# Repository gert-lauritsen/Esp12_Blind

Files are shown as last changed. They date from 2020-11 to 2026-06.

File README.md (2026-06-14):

# ESP12 Blind Controller

## Oversigt

ESP12 Blind Controller er en WiFi-baseret rullegardinstyring udviklet til IKEA-rullegardiner med et 3D-printet gearsystem og en stepmotor. Enheden styres via MQTT og understøtter automatisk registrering i Home Assistant gennem MQTT Discovery.

Projektet er baseret på en ESP8266 (ESP-12) og kan drive både:

* 28BYJ-48 stepmotor via ULN2003 driver
* Kraftigere stepmotor via DRV8825 driver

Positionen gemmes i EEPROM, så gardinet bevarer sin position efter genstart.

---

## Funktioner

* WiFi-forbindelse med fast IP-adresse
* MQTT styring
* Home Assistant MQTT Discovery
* Gemmer top-, bund- og aktuel position i EEPROM
* Ikke-blokerende stepmotorstyring
* Understøtter procentvis positionering (0-100%)
* Understøtter OPEN, CLOSE og STOP kommandoer
* MQTT Last Will & Testament (Online/Offline status)
* Understøttelse af endestopkontakter
* Automatisk Home Assistant Device-oprettelse

---

## Hardware

### ESP8266

Projektet er udviklet til:

* ESP-12E
* ESP-12F
* NodeMCU
* Wemos D1 Mini

### Stepmotor

Anbefalet:

* 28BYJ-48 5V stepmotor

### Motor Driver

#### ULN2003

Standardkonfiguration:

| ESP8266 GPIO | ULN2003 |
| --- | --- |
| GPIO5 | IN1 |
| GPIO0 | IN2 |
| GPIO4 | IN3 |
| GPIO2 | IN4 |

#### DRV8825

Alternativt kan projektet konfigureres til DRV8825 ved at deaktivere:

```cpp
#define ULN2003
```

og aktivere:

```cpp
#define DRV8825
```

---

## Endestopkontakter

Følgende indgange anvendes:

| Funktion | GPIO |
| --- | ---- |
| Top Endestop  | D3 |
| Bund Endestop | D6 |

Begge anvender:

```cpp
INPUT_PULLUP
```

---

## Konfiguration

### secrets.h

Opret filen:

```cpp
#pragma once

#define WIFI_SSID   "MyWifi"
#define WIFI_PASS   "MyPassword"

#define MQTT_SERVER "192.168.1.10"
#define MQTT_USER   "mqttuser"
#define MQTT_PASS   "mqttpassword"

#define LOCAL_IP    192,168,1,50
#define GATEWAY_IP  192,168,1,1
#define SUBNET_MASK 255,255,255,0
```

---

## Valg af Gardin

Hvert gardin skal have et unikt navn.

Eksempel:

```cpp
const char* room = "bed_room_right";
```

Andre eksempler:

```cpp
const char* room = "living_room";
const char* room = "office";
const char* room = "kitchen";
```

Dette navn anvendes til:

* MQTT topics
* Home Assistant Device ID
* Home Assistant Entity Name

---

## MQTT Topics

Hvis:

```cpp
room = "bed_room_right"
```

oprettes følgende topics.

### Kommandoer

#### Åbn

Topic:

```text
home/blind/bed_room_right/set
```

Payload:

```text
OPEN
```

#### Luk

```text
CLOSE
```

#### Stop

```text
STOP
```

#### Gå til position

```text
50
```

Flytter gardinet til 50%.

---

### Direkte positionering

Topic:

```text
home/blind/bed_room_right/set_position
```

Payload:

```text
35000
```

Flytter direkte til step-position.

---

### Gem bundposition

Topic:

```text
home/blind/bed_room_right/save_bottom
```

Payload kan være tom.

Aktuel position gemmes som bundposition.

---

### Gem topposition

Topic:

```text
home/blind/bed_room_right/save_top
```

Payload kan være tom.

Aktuel position gemmes som topposition.

---

## Status Topics

### Position i procent

```text
home/blind/bed_room_right/state
```

Eksempel:

```text
75
```

### Aktuel step-position

```text
home/blind/bed_room_right/CurrentPosition
```

Eksempel:

```text
52341
```

### Tilgængelighed

```text
home/blind/bed_room_right/availability
```

Mulige værdier:

```text
online
offline
```

---

## Home Assistant

Projektet anvender MQTT Discovery.

Discovery Topic:

```text
homeassistant/cover/esp8266_blind_<room>/config
```

Ved opstart registreres gardinet automatisk som:

* Cover Entity
* Device
* Availability Sensor

Ingen manuel YAML-konfiguration er nødvendig.

---

## EEPROM

Følgende data gemmes permanent:

| Adresse | Data |
| --- | --- |
| 0 | Bottom Position  |
| 4 | Top Position |
| 8 | Current Position |

Data gemmes automatisk når:

* Top position ændres
* Bund position ændres
* Gardinet når sin destination

---

## Første Opstart

Ved første opstart initialiseres:

```cpp
bottomPosition = 0;
topPosition = 70000;
currentPosition = 0;
```

Disse værdier bør efterfølgende kalibreres.

---

## Kalibrering

1. Kør gardinet til helt lukket position.
2. Send MQTT kommando til:

```text
home/blind/<room>/save_bottom
```

3. Kør gardinet til helt åben position.
4. Send MQTT kommando til:

```text
home/blind/<room>/save_top
```

5. Positionerne gemmes i EEPROM.

---

## Netværk

Projektet anvender statisk IP-adresse.

Konfiguration:

```cpp
WiFi.config(local_IP, gateway, subnet);
```

Hvis DHCP ønskes kan denne linje fjernes.

---

## Seriel Debug

Baudrate:

```text
115200
```

Ved opstart vises blandt andet:

```text
Connecting to WiFi
MQTT host: 192.168.1.10
Setup Completed
AA:BB:CC:DD:EE:FF
```

---

## Projektstruktur

```text
Esp12_Blind/
│
├── README.md
├── Schematic.png
│
├── Esp8266_blindController_HA/
│   ├── Esp8266_blindController_HA.ino
│   └── secrets.h
│
└── ES3P2_test/
    └── Esp32_blindController_HA/
```

---

## Kendte Begrænsninger

* Automatisk kalibrering er ikke implementeret.
* Endestopkontakter anvendes endnu ikke aktivt under normal drift.
* Positionering er baseret på step-tælling og ikke absolut feedback.
* Ved mekanisk slip kan positionen afvige.

---

## Fremtidige Forbedringer

* Automatisk kalibrering via endestop
* Web-interface
* OTA firmwareopdatering
* Hastighedsramper (Acceleration/Deceleration)
* Batteridrift
* Position backup til MQTT/Home Assistant

## Noter
Simple rullegardin styring baseret på Ikea rulle gardin og et 3D printet gear. Driver en lille stepper vha ULN2003.
I den nye hardware har jeg lagt ind at man også kan bruge en almindelig stepper driver til lidt mere highpower stepper

- Video [On Smarthome](https://www.facebook.com/Askob.dk/photos/a.409725012772869/409724829439554/?type=3&theater)
- [608ZZ kugleleje](https://arduinotech.dk/shop/kuglelejer/)
- [28BYJ-48](https://arduinotech.dk/shop/step-gear-motor-28byj-48-5v-4-phase-5-wire-dc-5v/) stepper motor

- [Schematic](https://github.com/gert-lauritsen/Esp12_Blind/blob/master/ESP12DualStepperPCB/RulleGardin.pdf)

---

## Referencer

* ESP8266
* Home Assistant MQTT Discovery
* PubSubClient
* ArduinoJson
* 28BYJ-48 Stepper Motor
* ULN2003 Driver
* DRV8825 Driver

## Licens

Projektet stilles til rådighed som open source. Tilpas og anvend frit på eget ansvar.

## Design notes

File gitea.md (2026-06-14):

# HowTo: Setup og brug af Gitea (lokal Docker-installation)

Denne guide beskriver:
- hvordan Gitea er sat op lokalt (Docker)
- hvordan GitHub-repos er migreret
- hvordan man arbejder lokalt og pusher til både GitHub og Gitea
- hvordan backup er sat op

Miljøet er en **lokal Linux-maskine**, der kører Docker, Home Assistant og Gitea.

---

## 1. Gitea – grundopsætning

### Web UI
- URL:  
  http://localhost:3000  
  eller  
  http://10.160.0.156:3000

### SSH
- Host: `localhost` / `10.160.0.156`
- Port: `2222`
- Brugernavn: `git`

---

## 2. Struktur på hosten

```text
/opt/stacks/
├── hass/
│   ├── compose.yaml
│   ├── hass-config/
│   ├── mosquitto/
│   ├── nodered/
│   └── zigbee2mqtt/
└── gitea/
    ├── compose.yaml
    └── data/
```
Backups ligger i:
```
/home/gert/backups/
├── hass/
└── gitea/
```

---

## 3. GitHub → lokal backup (alle repos)
```
mkdir -p ~/github-backup
cd ~/github-backup

```
```
gh repo list gert-lauritsen --limit 1000 --json nameWithOwner \
  -q '.[].nameWithOwner' | while read repo; do
    git clone git@github.com:$repo.git
done
```

---

## 4. Migrering til Gitea (HTTPS push)

Repos oprettes via Gitea API og pushes derefter lokalt.

Eksempel for ét repo:
```
cd ~/github-backup/RepoNavn

git remote add gitea http://localhost:3000/gert/RepoNavn.git
git push --all gitea
git push --tags gitea
```

---

## 5. Arbejde på et eksisterende lokalt projekt
Eksempel: WalktemScript

Repo findes allerede lokalt og på GitHub.
Gå ind i repo
cd /path/to/WalktemScript
Tjek eksisterende remotes

```
git remote -v
```

Tilføj Gitea som ekstra remote
```
git remote add gitea http://10.160.0.156:3000/gert/WalktemScript.git
```

Push til Gitea
```
git push gitea
git push --all gitea
git push --tags gitea
```
Nu findes repoet både på:

GitHub (origin)

Gitea (gitea)

---

## 6. Gøre Gitea til standard push (valgfrit)
```
git branch --set-upstream-to=gitea/main
```
(Eller master, afhængigt af branch-navn.)

---

## 7. Push til både GitHub og Gitea

Manuelt:
```
git push origin
git push gitea
```
Alias (globalt):
```
git config --global alias.pushall '!git push origin && git push gitea'
```
Brug:

git pushall

---

## 8. Backup (kritisk)
Kør samlet backup
```
sudo /home/gert/backups/backup_all.sh
```
Dette:

stopper Docker stacks midlertidigt
laver tar.gz backups af:

```
/opt/stacks/hass

/opt/stacks/gitea
```
starter stacks igen

Backups roteres automatisk.

---

## 9. Restore (kort)
Gitea

```
cd /opt/stacks
docker compose -f gitea/compose.yaml down
rm -rf gitea
tar -xzf ~/backups/gitea/gitea_YYYY-MM-DD_HH-MM.tar.gz -C /opt/stacks
docker compose -f gitea/compose.yaml up -d
```

## Home Assistant

Samme princip med hass.

---

## 10. Anbefalet workflow

Udvikling lokalt

Push til Gitea som primær
GitHub evt. som mirror / public visning
Regelmæssig backup (lokal + offsite)

Noter

Brug HTTPS + token for enkelhed
SSH kan aktiveres senere, men er ikke påkrævet
Gitea-data er selvstændig og uafhængig af GitHub

---

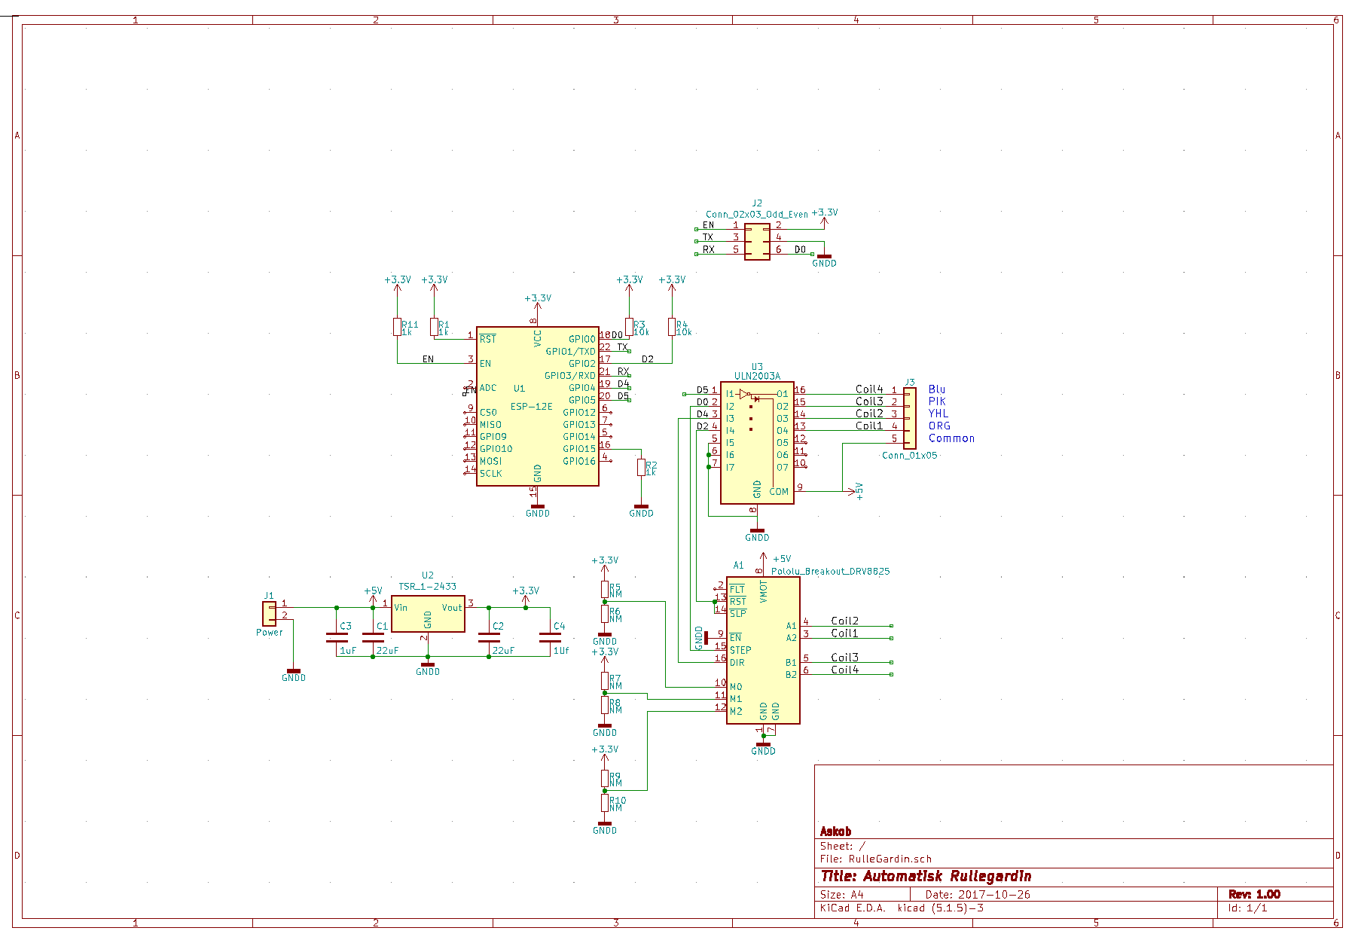
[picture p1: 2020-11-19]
Schematic.png

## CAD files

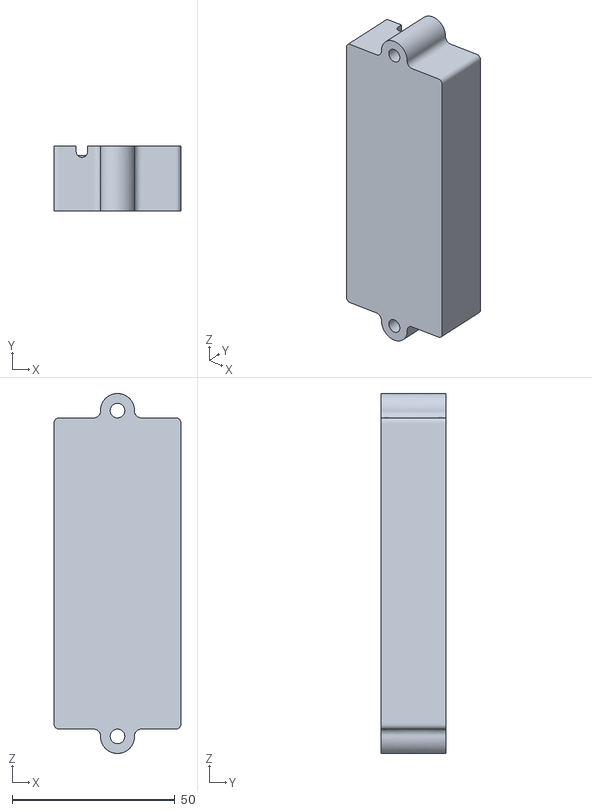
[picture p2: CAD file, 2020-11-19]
GearBoks/files/box.stl
39.0 x 20.0 x 110.7

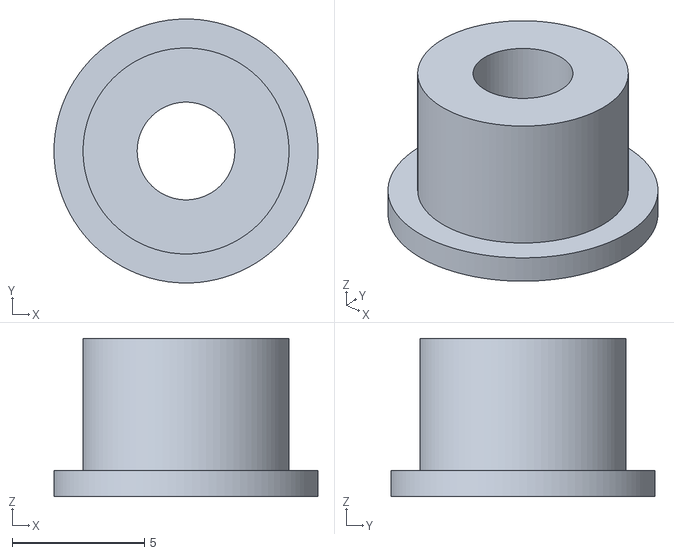
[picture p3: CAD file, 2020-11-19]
GearBoks/files/20170620_center_pin.stl
10.00 x 10.00 x 6.00

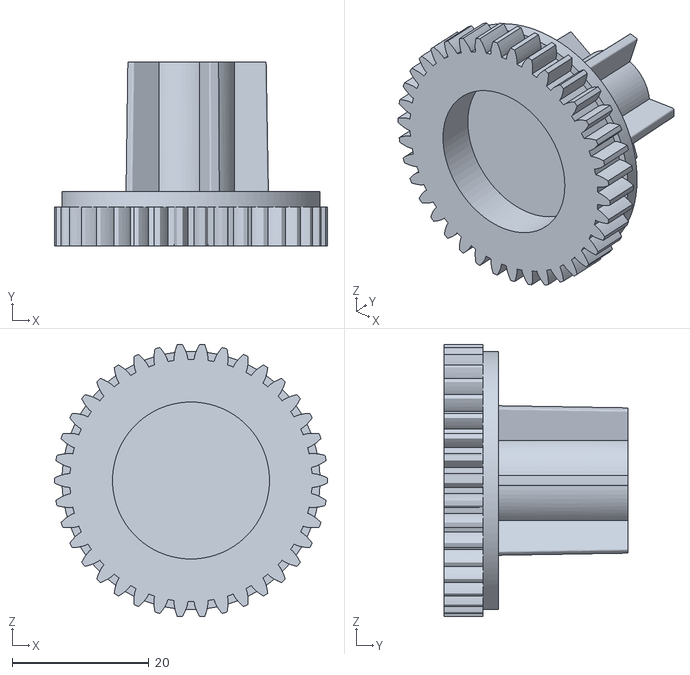
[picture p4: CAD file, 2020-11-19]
GearBoks/files/20170821_blind_holder_22mm.stl
40.0 x 27.0 x 39.9

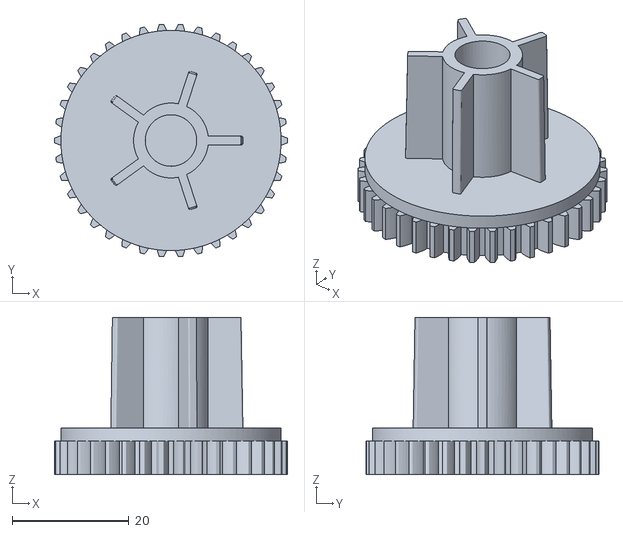
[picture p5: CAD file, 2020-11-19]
GearBoks/files/20170620_blind_holder_23.5mm.stl
40.0 x 39.9 x 27.0

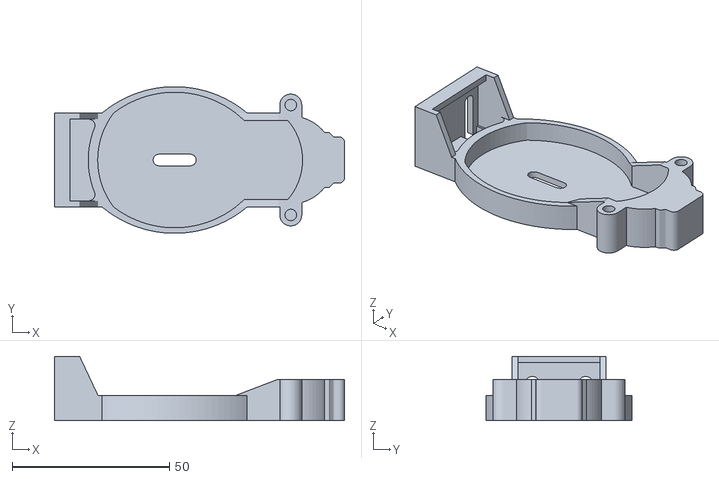
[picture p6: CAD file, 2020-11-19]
GearBoks/files/20170620_holder.stl
92.3 x 46.6 x 20.5

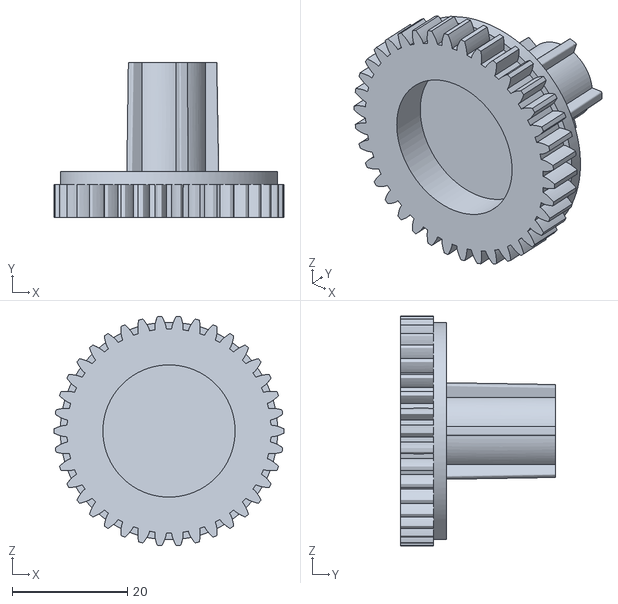
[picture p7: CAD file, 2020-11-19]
GearBoks/files/20171220_blind_holder_17mm.stl
40.0 x 27.0 x 39.9

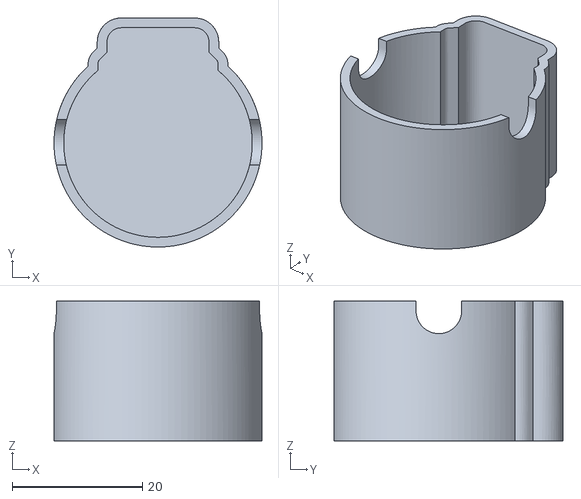
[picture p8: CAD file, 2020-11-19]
GearBoks/files/20170620_box.stl
32.0 x 35.2 x 21.5

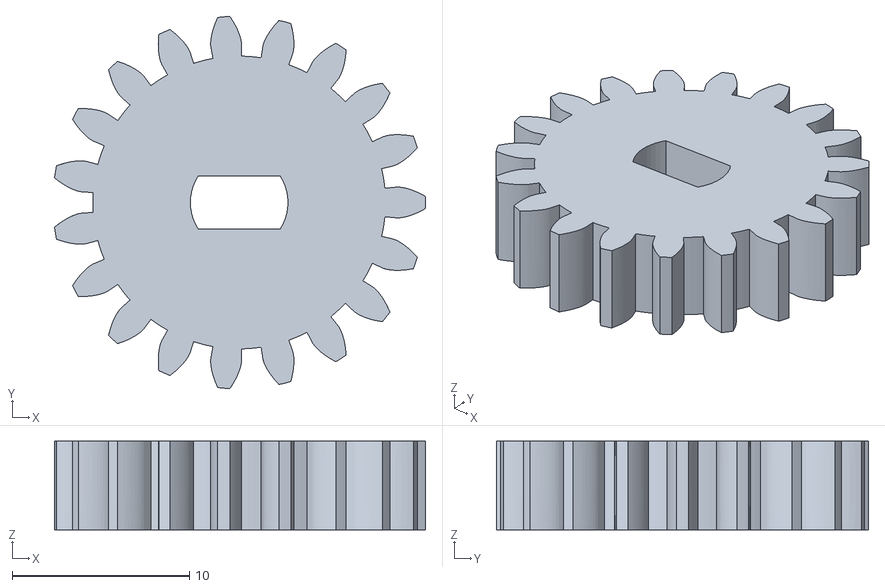
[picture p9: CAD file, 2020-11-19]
GearBoks/files/20170620_motor_gear.stl
20.9 x 21.0 x 5.00

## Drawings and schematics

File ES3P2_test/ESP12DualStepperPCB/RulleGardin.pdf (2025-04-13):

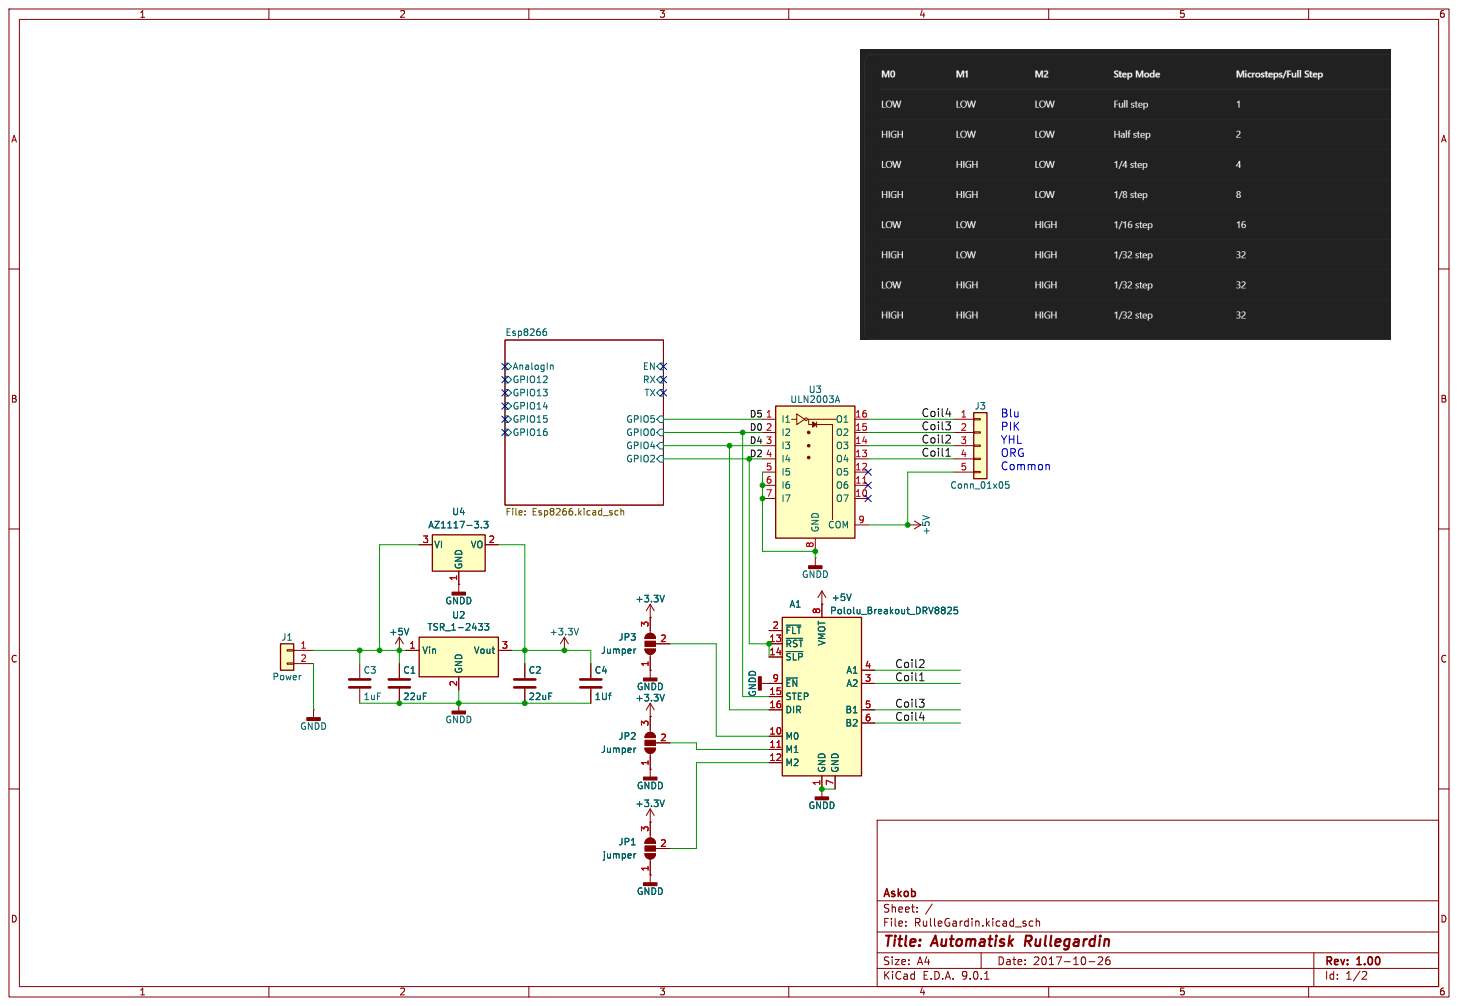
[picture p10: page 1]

3 A1 Pololu_Breakout_DRV8825 ~{FLT} 2 ~{RST} 13 ~{SLP} 14 ~{EN} 9 STEP 15 DIR 16 M0 10 M1 11 M2 12 VMOT

File: RulleGardin.kicad_sch Sheet: / Askob

Id: 1/2 Title: Automatisk Rullegardin

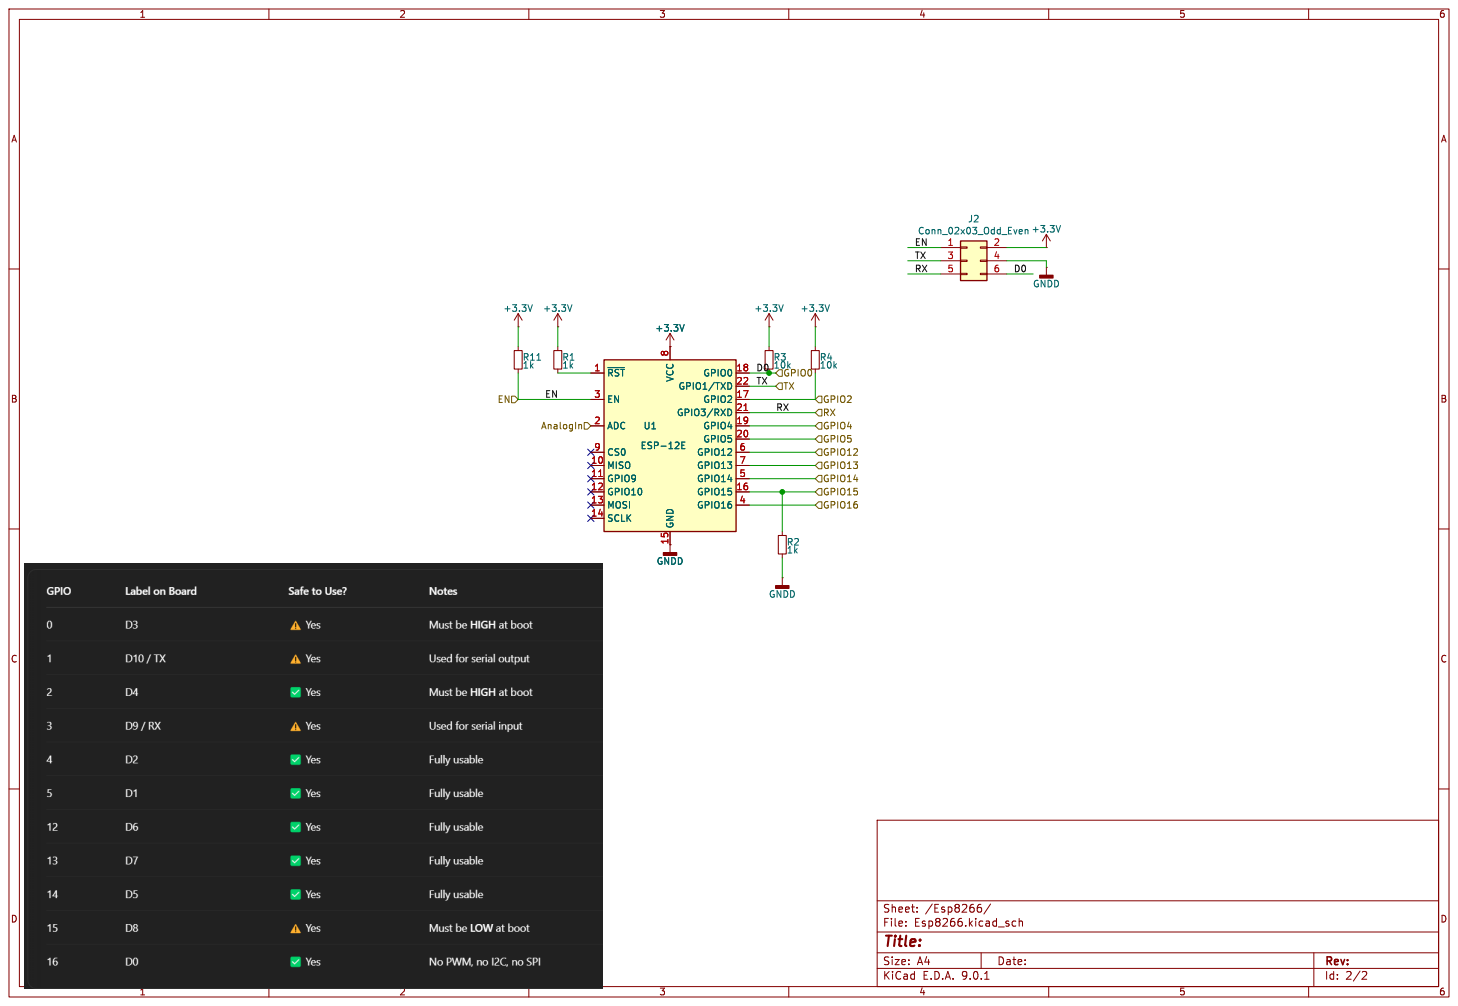
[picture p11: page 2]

8 GND 15 GPIO0 18 GPIO1/TXD 22 GPIO2 17 GPIO3/RXD 21 GPIO4 19 GPIO5 20 GPIO12 6 GPIO13 7 GPIO14 5 GPIO15 16 GPIO16 4 U1 ESP-12E

8 GND 15 GPIO0 18 GPIO1/TXD 22 GPIO2 17 GPIO3/RXD 21 GPIO4 19 GPIO5 20 GPIO12 6 GPIO13 7 GPIO14 5 GPIO15 16 GPIO16 4 GNDD

Id: 2/2 Title: File: Esp8266.kicad_sch Sheet: /Esp8266/ GNDD

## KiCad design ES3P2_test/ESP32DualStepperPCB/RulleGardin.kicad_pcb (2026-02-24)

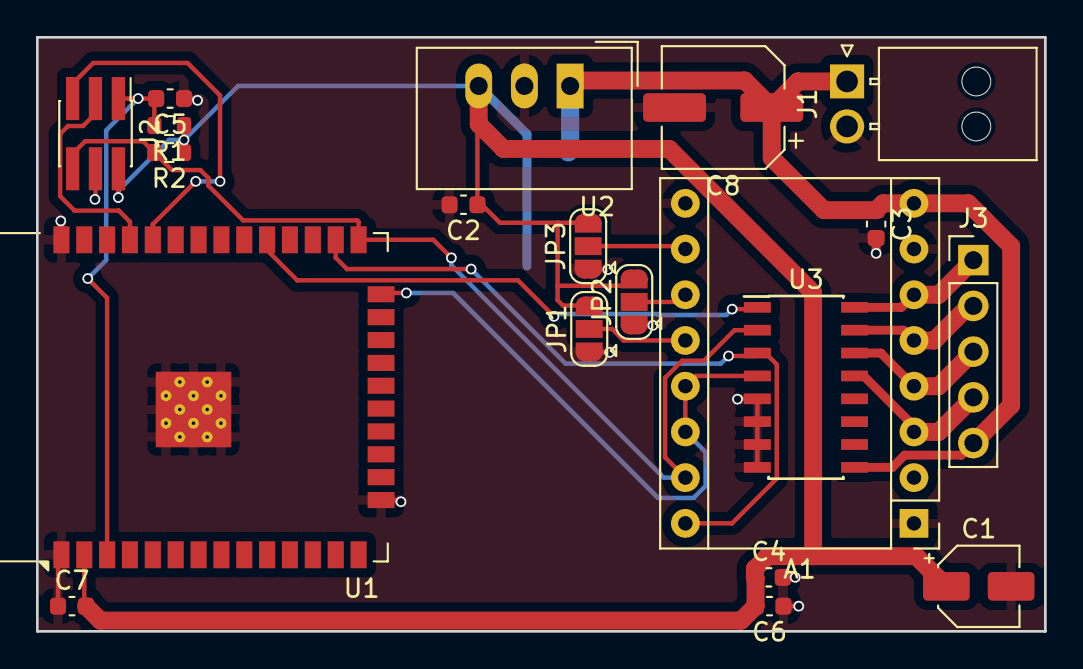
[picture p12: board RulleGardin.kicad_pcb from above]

Board: 2 copper layers, 56.0 x 33.0 mm, 21 parts (1 on the bottom side), 17 nets.

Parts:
A1: Pololu_Breakout_DRV8825; Pololu_Breakout-16_15.2x20.3mm
C1: 10u; CP_Elec_4x5.4
C2, C3, C4: 1uF; C_0603_1608Metric
C5, C6, C7: 0.1uf; C_0603_1608Metric
C8: 10u; CP_Elec_6.3x7.7
J1: Power; Molex_NanoFit_1x02x2.50mm_Angled
J2: Prog; PinHeader_2x03_P1.27mm_Vertical_SMD
J3: Conn_01x05; Pin_Header_Straight_1x05_Pitch2.54mm
JP1: jumper; SolderJumper-3_P1.3mm_Open_RoundedPad1.0x1.5mm
JP2, JP3: Jumper; SolderJumper-3_P1.3mm_Open_RoundedPad1.0x1.5mm
R1, R2: 10K; R_0603_1608Metric
U1: ESP32-WROOM-32
U2: TSR_1-2433; Converter_DCDC_TRACO_TSR-1_THT
U3: ULN2003A; SOIC-16_3.9x9.9mm_Pitch1.27mm
U4: AZ1117-3.3; SOT-223-3_TabPin2

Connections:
+3.3V: C1.1, C2.1, C4.1, C6.2, C7.2, J2.2, JP1.3 (B), JP2.3 (B), JP3.3 (B), R1.1, R2.1, U1.2 (VDD), U2.3 (Vout), U4.2 (VO)
+5V: A1.8 (VMOT), C3.1, C8.1, J1.1, J3.5, U2.1 (Vin), U3.9 (COM), U4.3 (VI)
/Coil1: A1.3 (A2), J3.4, U3.13 (O4)
/Coil2: A1.4 (A1), J3.3, U3.14 (O3)
/Coil3: A1.5 (B1), J3.2, U3.15 (O2)
/Coil4: A1.6 (B2), J3.1, U3.16 (O1)
/D2: A1.13 (~RST), A1.14 (~SLP), U1.24 (IO2), U3.4 (I4)
/D4: A1.16 (DIR), U1.26 (IO4), U3.3 (I3)
/D5: U1.29 (IO5), U3.1 (I1)
D0: A1.15 (STEP), J2.6, R2.2, U1.25 (IO0), U3.2 (I2)
EN: C5.2, J2.1, R1.2, U1.3 (EN)
GND: A1.1 (GND), A1.7 (GND), A1.9 (~EN), C1.2, C2.2, C3.2, C4.2, C5.1, C6.1, C7.1, C8.2, J1.2, J2.4, JP1.1 (A), JP2.1 (A), JP3.1 (A), U1.1 (GND), U1.15 (GND), U1.38 (GND), U1.39 (GND), U2.2 (GND), U3.5 (I5), U3.6 (I6), U3.7 (I7), U3.8 (GND), U4.1 (GND)
unnamed: A1.10 (M0), JP3.2 (C)
unnamed: A1.11 (M1), JP2.2 (C)
unnamed: A1.12 (M2), JP1.2 (C)
RX: J2.5, U1.34 (RXD0/IO3)
TX: J2.3, U1.35 (TXD0/IO1)

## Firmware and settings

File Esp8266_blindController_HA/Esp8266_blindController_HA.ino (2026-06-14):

// ESP8266 Blind Controller with ULN2003 and MQTT Auto-Discovery for Home Assistant (non-blocking)
#ifdef ESP8266
#include <ESP8266WiFi.h>
#include <ESP8266mDNS.h>
#elif defined(ESP32)
#include <WiFi.h>
#include <ESPmDNS.h>
#endif
#include <PubSubClient.h>
#include <EEPROM.h>
#include <ArduinoJson.h>
#include "secrets.h"
//#include <Stepper_28BYJ_48.h>

#ifdef ESP8266
#define IN1_PIN 5
#define IN2_PIN 0
#define IN3_PIN 4
#define IN4_PIN 2
#define LIMIT_TOP_PIN D3
#define LIMIT_BOTTOM_PIN D6
#elif defined(ESP32)
#define IN1_PIN 5
#define IN2_PIN 0
#define IN3_PIN 4
#define IN4_PIN 2
#define LIMIT_TOP_PIN 3
#define LIMIT_BOTTOM_PIN 15
#endif
#define ReverseSetup true
#define UpdateStatusTimeout 10000
#define ULN2003
//#define DRV8825

const char* ssid = WIFI_SSID;
const char* password = WIFI_PASS;
const char* mqtt_server = MQTT_SERVER;
const char* mqtt_user = MQTT_USER;
const char* mqtt_pass = MQTT_PASS;

const char* room = "bed_room_rigth"; //Has to uniq
//const char* room = "bed_room_left"; //Has to uniq

// Build a stable device identifier for Home Assistant "device" grouping (ESP8266-only)
String haDeviceId() {
  uint32_t chip = ESP.getChipId();
  char buf[32];
  // include room to avoid collisions if you ever clone flash to another unit without changing room
  snprintf(buf, sizeof(buf), "esp8266_blind_%06X_%s", chip, room);
  return String(buf);
}

//const char* room = "bed_room_left";
//const char* room = "main_room_test";

const uint8_t stepSequence[8][4] = {
  {1, 0, 0, 0},
  {1, 1, 0, 0},
  {0, 1, 0, 0},
  {0, 1, 1, 0},
  {0, 0, 1, 0},
  {0, 0, 1, 1},
  {0, 0, 0, 1},
  {1, 0, 0, 1}
};

const uint8_t fullStepSequence[4][4] = {
  {1, 1, 0, 0},  // Step 1
  {0, 1, 1, 0},  // Step 2
  {0, 0, 1, 1},  // Step 3
  {1, 0, 0, 1}   // Step 4
};


IPAddress local_IP(LOCAL_IP);
IPAddress gateway(GATEWAY_IP);
IPAddress subnet(SUBNET_MASK);

WiFiClient espClient;
PubSubClient client(espClient);

long topPosition = 0;
long bottomPosition = 0;
long currentPosition = 0;
long targetPosition = 0;
long lastupdatestatus = 0; 

bool calibrated = false;
bool moving = false;
bool direction = true;
bool StepValue = false;
//Stepper_28BYJ_48 small_stepper(IN1_PIN, IN2_PIN, IN3_PIN, IN4_PIN); //Initiate stepper driver HW ver 1

#define EEPROM_SIZE 64


int stepIndex = 0;
unsigned long lastStepTime = 0;
unsigned long stepInterval = 1200; // microseconds between steps

void setup_wifi() {
  Serial.println("Connecting to: "+String(ssid)); 
  WiFi.config(local_IP, gateway, subnet);
  WiFi.begin(ssid, password);
  while (WiFi.status() != WL_CONNECTED) {
    Serial.print(".");
    delay(500);
  }  
  Serial.println("");
    // Set hostname, e.g., "myesp"
  if (!MDNS.begin(String(room))) {
    Serial.println("Error starting mDNS");
    return;
  }
}

void publishDiscoveryConfig() {
  // Home Assistant MQTT Discovery for a Cover entity (blind)
  // Discovery topic format: homeassistant/<component>/<unique_id>/config
  String uniqueId = "esp8266_blind_" + String(room);
  String topic = "homeassistant/cover/" + uniqueId + "/config";

  String base = "home/blind/" + String(room);
  // Use a dedicated availability topic. If you previously published to
  // "home/blind/<room>/availability" (common pattern) and an old retained
  // "offline" is still there, Home Assistant will keep the entity unavailable
  // until it receives "online" on the *same* topic.
  //
  // So we standardize on "/availability" here.
  String statusTopic = base + "/availability";

  StaticJsonDocument<768> doc;

  // Friendly name
  String displayName = String(room);
  displayName.replace("_", " ");
  doc["name"] = displayName + " Blind";

  // Topics
  doc["command_topic"]       = base + "/set";           // OPEN/CLOSE/STOP (and also used by your code)
  doc["position_topic"]      = base + "/state";         // 0-100 position reports
  doc["set_position_topic"]  = base + "/set_position";  // numeric 0-100 set

  // Availability (shows device online/offline)
  doc["availability_topic"]   = statusTopic;
  doc["payload_available"]    = "online";
  doc["payload_not_available"]= "offline";

  // Entity identity
  doc["unique_id"] = uniqueId;
  doc["device_class"] = "blind";

  // ---- Device info (this is what makes it show up as a Device in HA) ----
  JsonObject dev = doc.createNestedObject("device");
  JsonArray ids = dev.createNestedArray("identifiers");
  ids.add(haDeviceId());                 // stable ID per unit
  dev["name"] = displayName + " Blind Controller";
  dev["manufacturer"] = "DIY";
  dev["model"] = "ESP8266 Blind Controller (ULN2003/DRV8825)";
  dev["sw_version"] = "1.0";
  dev["suggested_area"] = displayName;

  char buffer[768];
  size_t n = serializeJson(doc, buffer, sizeof(buffer));
  bool success = client.publish(topic.c_str(), (const uint8_t*)buffer, n, true);

  Serial.print("Discovery publish result: ");
  Serial.println(success ? "SUCCESS" : "FAILED");
}
/*
void stepMotor(bool dir) {
  if (dir) small_stepper.step(-1);
  else small_stepper.step(1);
}
*/
#ifdef ULN2003
void stepMotor(bool dir) {
  if (ReverseSetup) dir=!dir;
  if (dir) stepIndex = (stepIndex + 1) % 8;
  else stepIndex = (stepIndex + 7) % 8;
  digitalWrite(IN1_PIN, stepSequence[stepIndex][0]);
  digitalWrite(IN2_PIN, stepSequence[stepIndex][1]);
  digitalWrite(IN3_PIN, stepSequence[stepIndex][2]);
  digitalWrite(IN4_PIN, stepSequence[stepIndex][3]);
}
#endif

#ifdef DRV8825
void stepMotor(bool dir) {
  if (ReverseSetup) dir=!dir;
  StepValue=!StepValue;
  digitalWrite(IN4_PIN, 0); //Set reset low
  digitalWrite(IN2_PIN, StepValue);
  digitalWrite(IN3_PIN, dir);
}
#endif

/*
void stepMotor(bool dir) {
  if (dir) stepIndex = (stepIndex + 1) % 4;
  else stepIndex = (stepIndex + 3) % 4;
  digitalWrite(IN1_PIN, fullStepSequence[stepIndex][0]);
  digitalWrite(IN2_PIN, fullStepSequence[stepIndex][1]);
  digitalWrite(IN3_PIN, fullStepSequence[stepIndex][2]);
  digitalWrite(IN4_PIN, fullStepSequence[stepIndex][3]);
}*/

void moveTo(long target) {
  targetPosition = target;
  direction = (targetPosition > currentPosition);
  if (target != currentPosition) {
    moving = true;
    String StatusTopic= "home/blind/" + String(room) + "/target";
    client.publish(StatusTopic.c_str(), String(target).c_str(), true);
    Serial.println("New Target: "+String(target));
  }  
}

void stop() {
 moving=false;
 digitalWrite(IN1_PIN,0);
 digitalWrite(IN2_PIN,0);
 digitalWrite(IN3_PIN,0);
 digitalWrite(IN4_PIN,0);
}

void updateMotor() {
  if (!moving) return;
  if ((micros() - lastStepTime) >= stepInterval) {
    lastStepTime = micros();
    stepMotor(direction);
    currentPosition += direction ? 1 : -1;
    if (currentPosition == targetPosition) {
      stop();
      publishState();
      saveLimits();
    }
  }
  if ((millis() - lastupdatestatus) >= UpdateStatusTimeout) {
    lastupdatestatus=millis();
    publishState();
  }    
}

void calibrate() {
 /* while (digitalRead(LIMIT_BOTTOM_PIN) == HIGH) {
    stepMotor(false);
    delay(5);
    currentPosition--;
  }
  bottomPosition = currentPosition;
  delay(500);
  while (digitalRead(LIMIT_TOP_PIN) == HIGH) {
    stepMotor(true);
    delay(5);
    currentPosition++;
  }
  topPosition = currentPosition;
  saveLimits();
  calibrated = true;
  publishState();*/
}

void callback(char* topic, byte* payload, unsigned int length) {
  String msg;
  for (unsigned int i = 0; i < length; i++) msg += (char)payload[i];
  msg+="\0";
  Serial.print(topic);
  Serial.print(" ");
  Serial.println(msg);
  String setTopic = "home/blind/" + String(room) + "/set";
  String calibrateTopic = "home/blind/" + String(room) + "/calibrate";
  if (String(topic) == setTopic) {
    if (strstr(msg.c_str(),"OPEN")!=NULL) {
      moveTo(topPosition);
      Serial.println("Opens blinds");
    }  
    else if (strstr(msg.c_str(),"CLOSE")!=NULL) {
      moveTo(bottomPosition);
      Serial.println("Closing blinds");
    }  
    else if (strstr(msg.c_str(),"STOP")!=NULL) {
      stop();
    }  
    else {
      int percent = msg.toInt();
      long range = topPosition-bottomPosition;
      if (range == 0) return;
      long target = bottomPosition + ((range * percent) / 100);
      moveTo(target);
    }
    Serial.println("Bottom:"+String(bottomPosition)+" Top: "+String(topPosition)+" Current "+String(currentPosition));  
  }  
  if (String(topic) == calibrateTopic) {
    calibrate();
  }

  if (String(topic) == "home/blind/" + String(room) + "/save_bottom") {
    bottomPosition = currentPosition;
    saveLimits();
    setTopic ="home/blind/" + String(room) + "/bottom_value";
    client.publish(setTopic.c_str(), String(bottomPosition).c_str(), true);
    Serial.println("Bottom position saved.");
  }
  if (String(topic) == "home/blind/" + String(room) + "/save_top") {
    topPosition = currentPosition;
    saveLimits();
    setTopic ="home/blind/" + String(room) + "/top_value";
    client.publish(setTopic.c_str(), String(topPosition).c_str(), true);
    Serial.println("Top position saved.");
  }
  if (String(topic) == "home/blind/" + String(room) + "/set_position") {
    Serial.println("set_position");
    int target = String((char*)payload).toInt();
    moveTo(target);
  } 
}

void reconnect() {
  while (!client.connected()) {
    String clientName = "Blind_" + String(room);

    // Must match discovery availability_topic
    String willTopic = String("home/blind/") + room + "/availability";

    bool ok = false;

    // If no MQTT username is configured, use the connect() overload without auth
    if (mqtt_user == nullptr || mqtt_user[0] == '\0') {
      ok = client.connect(
        clientName.c_str(),
        willTopic.c_str(),   // will topic
        0,                   // will QoS
        true,                // will retained
        "offline"            // will message
      );
    } else {
      ok = client.connect(
        clientName.c_str(),
        mqtt_user,
        mqtt_pass,
        willTopic.c_str(),   // will topic
        0,                   // will QoS
        true,                // will retained
        "offline"            // will message
      );
    }

    if (ok) {
      // Publish online retained so HA immediately marks entity available
      bool success = client.publish(willTopic.c_str(), "online", true);
      Serial.print("Mqtt Online result: ");
      Serial.println(success ? "SUCCESS" : "FAILED");

      // Subscribe to your control topics (unchanged)
      String setTopic            = String("home/blind/") + room + "/set";
      String calibrateTopic      = String("home/blind/") + room + "/calibrate";
      String setPositionTopic    = String("home/blind/") + room + "/set_position";
      String saveTopTopic        = String("home/blind/") + room + "/save_top";
      String saveBottomTopic     = String("home/blind/") + room + "/save_bottom";

      client.subscribe(setTopic.c_str());
      client.subscribe(calibrateTopic.c_str());
      client.subscribe(setPositionTopic.c_str());
      client.subscribe(saveTopTopic.c_str());
      client.subscribe(saveBottomTopic.c_str());

      client.publish("home/blind/status", "online", true);

      publishDiscoveryConfig();
    } else {
      // Optional: print state to diagnose auth/timeout issues
      Serial.print("MQTT connect failed, state=");
      Serial.println(client.state());

      delay(5000);
    }
  }
}

void saveLimits() {
  EEPROM.put(0, bottomPosition);
  EEPROM.put(sizeof(long), topPosition);
  EEPROM.put(sizeof(long)*2, currentPosition);
  EEPROM.commit();
  Serial.println("Save Bottom:"+String(bottomPosition)+" Top: "+String(topPosition)+" Current "+String(currentPosition));
}

void loadLimits() {
  EEPROM.get(0, bottomPosition);
  EEPROM.get(sizeof(long), topPosition);
  EEPROM.get(sizeof(long)*2, currentPosition);
  calibrated = true;
  Serial.println("Load Bottom:"+String(bottomPosition)+" Top: "+String(topPosition)+" Current "+String(currentPosition));
}

void publishState() {
  String stateTopic = "home/blind/" + String(room) + "/state";
  long range = topPosition - bottomPosition;
  if (range == 0) {
    client.publish(stateTopic.c_str(), "0", true);
    return;
  }
  int percent = (currentPosition - bottomPosition) * 100 / range;
  percent = constrain(percent, 0, 100);
  client.publish(stateTopic.c_str(), String(percent).c_str(), true);
  stateTopic = "home/blind/" + String(room) + "/CurrentPosition";
  client.publish(stateTopic.c_str(), String(currentPosition).c_str(), true);
}

void setup() {
  Serial.begin(115200);
  Serial.println("");
  Serial.println("-------------------------------------------------------------------");  
  pinMode(LIMIT_TOP_PIN, INPUT_PULLUP);
  pinMode(LIMIT_BOTTOM_PIN, INPUT_PULLUP);
  pinMode(IN1_PIN, OUTPUT);
  pinMode(IN2_PIN, OUTPUT);
  pinMode(IN3_PIN, OUTPUT);
  pinMode(IN4_PIN, OUTPUT);

  EEPROM.begin(EEPROM_SIZE);
  loadLimits();
  if (topPosition<=0) {
    bottomPosition=0;
    topPosition=70000;
    currentPosition=0;
    saveLimits();
    Serial.println("Init value loaded");
    Serial.println("Bottom:"+String(bottomPosition)+" Top: "+String(topPosition)+" Current "+String(currentPosition));
  }
  setup_wifi();
  Serial.print("MQTT host: "); Serial.println(mqtt_server);

  client.setServer(mqtt_server, 1883);
  client.setCallback(callback);
  client.setBufferSize(1024);

  publishState();
  Serial.println("Setup Completed");
  Serial.println(WiFi.macAddress());
  Serial.println("-------------------------------------------------------------------");
}

void loop() {
  if (!client.connected()) reconnect();
  client.loop();
  updateMotor();
}

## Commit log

2025-04-13 PCB update
    [Esp8266.kicad_sch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]
2025-04-14 rettet de sidste fejl
2025-04-15 Added ESP32 Since esp8266 dont work with my router
    [Esp8266.kicad_sch, RulleGardin.kicad_pcb, RulleGardin.kicad_sch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]
2025-04-15 fund that its the dhcp that the problem, so now with static IP
    [RulleGardin.kicad_pcb, RulleGardin.kicad_sch]
2026-02-24 med device understøttelse
    [RulleGardin.kicad_pcb, RulleGardin.kicad_sch, StdEsp32_S2.kicad_sch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]
